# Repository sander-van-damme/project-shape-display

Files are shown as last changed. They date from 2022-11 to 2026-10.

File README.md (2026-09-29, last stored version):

<!-- © 2024 Sander Van Damme - All Rights Reserved. -->

# D&D battle-map shape display

This repository develops a tabletop shape display for physical Dungeons & Dragons battle maps: a dense grid of square or rectangular columns that can form terrain, walls, platforms, stairs, pits and other relief while remaining usable with miniatures.

## Engineering flow

The numbered root directories are intentionally ordered. Read them as the project argument from problem definition to integrated designs:

1. [`01-project-description/`](01-project-description/) — what is being built and why, including the [standing Board mandate](01-project-description/board-mandate.md).
2. [`02-design-criteria/`](02-design-criteria/) — requirements, scale, fabrication context and success criteria.
3. Engineering knowledge used to construct solutions:
   - [`03-engineering-knowledge/`](03-engineering-knowledge/) — knowledge model, sources and cross-cutting synthesis.
   - [`03.1-engineering-disciplines/`](03.1-engineering-disciplines/) — analogous engineering fields.
   - [`03.2-engineering-mechanisms/`](03.2-engineering-mechanisms/) — concrete reusable mechanisms.
   - [`03.3-engineering-principles/`](03.3-engineering-principles/) — transferable design principles.
4. [`04-architecture-candidates/`](04-architecture-candidates/) — Shape Display-specific combinations of mechanisms and principles.
5. [`05-research-questions/`](05-research-questions/) — unresolved hypotheses, investigations and research directions.
6. [`06-experiments/`](06-experiments/) — calculations, simulations, CAD, prototypes and physical tests that generate evidence.
7. [`07-evidence-and-decisions/`](07-evidence-and-decisions/) — consolidated evidence, architecture investigations and durable decisions.
8. [`08-integrated-designs/`](08-integrated-designs/README.md) — the **single stage for complete machine architectures**. Stage 08 may hold **multiple** integrated-design packages, each with its own status (see the [stage index](08-integrated-designs/README.md)); a design becoming integrated does **not** delete or overwrite previous integrated designs.

The numbered flow **terminates at 08**. A new machine architecture does **not** receive a new
numbered root directory — see [New designs do not get new numbered stages](#new-designs-do-not-get-new-numbered-stages) below.

## Core target

The detailed requirements live in [`02-design-criteria/README.md`](02-design-criteria/README.md). The current target includes approximately 400 × 400 mm active area, about 5.08 mm or finer pitch, roughly 6,200–6,400 cells at full scale, at least 40 mm provisional vertical travel, regional updates, a playable full-map change in under 30 seconds, and tight purchased-component cost limits.

## How knowledge should move

```text
project description
  -> design criteria
  -> disciplines
  -> mechanisms
  -> principles
  -> architecture candidates
  -> research questions
  -> experiments
  -> evidence and decisions
  -> integrated designs (08, may hold several)
  -> new questions / updated knowledge
```

Experiments are evidence, not the primary place to store durable engineering knowledge. Conclusions that survive testing should be fed back into the relevant mechanism, principle or architecture section.

## New designs do not get new numbered stages

The root numbers describe the **engineering lifecycle**, not architecture versions. Do not
create `09-*`, `10-*`, `11-*`, … for a new machine.

- A new **idea / mechanism / system concept** belongs in [`04-architecture-candidates/`](04-architecture-candidates/).
- Evidence-generating work (calculations, simulations, CAD, screens, falsification tests)
  belongs in [`06-experiments/`](06-experiments/).
- Durable conclusions, comparisons and selection/rejection decisions belong in
  [`07-evidence-and-decisions/`](07-evidence-and-decisions/).
- Only an architecture that has matured into a **complete machine** is placed under
  [`08-integrated-designs/<semantic-design-name>/`](08-integrated-designs/README.md).
  Use meaning-bearing names, never `design-1/`, `design-2/`, or a new number.

Promotion into stage 08 requires at minimum a coherent full-system mechanism, interaction with
all important product requirements, timing/cost/scalability/reliability analysis, explicit
unresolved risks, enough CAD/calculation evidence to evaluate the architecture, and an
evidence/decision record explaining the promotion. Stage 08 must not be flooded with raw
exploration.

## Agent autonomy and repository operations

This repository is an autonomous engineering workspace. Paperclip agents are trusted to manage
ordinary repository work without waiting for board approval or rejection.

- Agents may create, modify, move, or delete repository files; create branches and commits; open,
  update, review, close, and **merge pull requests themselves**.
- **No board approval is required for merges, ordinary refactors, experiments, design decisions, or
  promotion of an architecture when the documented engineering evidence supports it.**
- Branches, PRs, reviews, and checks are useful for traceability and engineering quality; they are
  **not permission gates**.
- Do not block ongoing work waiting for a board response. Escalation is reserved for genuinely
  exceptional actions outside normal project iteration (for example, destroying/replacing the
  repository as a whole).
- Never commit credentials, tokens, private keys, or other secrets.

## Useful entry points

- [Design criteria](02-design-criteria/README.md)
- [Engineering knowledge model](03-engineering-knowledge/README.md)
- [Architecture candidates](04-architecture-candidates/)
- [Research questions](05-research-questions/)
- [Experiment guide](06-experiments/README.md)
- [Evidence and decisions](07-evidence-and-decisions/)
- [Integrated designs (stage 08)](08-integrated-designs/README.md)

## Copyright

© 2024-2026 Sander Van Damme - All Rights Reserved.

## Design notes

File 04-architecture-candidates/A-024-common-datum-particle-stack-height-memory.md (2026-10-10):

---
status: candidate
builds-on: [M-001, P-009]
---

# Common-datum particle-stack height memory

A column follower rests on a counted stack of spheres in a vertical tube. The
number of particles stores height; compressive contacts and a grounded bottom
fork support the load. A travelling row of feeders docks at the **fixed bottom
of every stack**, avoiding acquisition of a foot at an unknown height. This is
solid-length storage, distinct from trapped fluid, tensile winding and the
binary moving structural layers. The follower needs guidance and a downward
return bias; particle removal alone cannot pull a jammed follower down.

Proposed transaction: a pocketed pusher supports the stack, unloads the fork,
transfers one particle in/out, returns the grounded fork, seats and proves support,
then repeats or undocks. Two support levels are needed during exchange; the fork
cannot simply withdraw beneath a loaded stack. Shared powered feed strokes plus
individually selected head couplings provide addressing. Unchanged forks remain
engaged. The transfer, return, actuator arrest and retained selection are open
mechanisms, not supplied by the existence of beads or a clearance section.

Count pulses are insufficient readback: use an underside follower-height mark
and support-proof step before undocking. A missed/doubled particle, bridging or
false acceptance leaves a wrong or unsupported cell. Stop with the head supported,
retain selection, reverse at most one transfer after readback, then isolate and
service the tube. A common reader/feed fault may affect an entire bank. Shared
reservoir and recirculation must work on repeated arbitrary maps, including an
all-high map; spare storage cannot be omitted.

E-126 rejects the bounded **four-rest-to-rest-stroke feeder** on throughput,
including 320 heads. It does not reject continuous pocketed feeding. The tested
4-mm sphere scenarios need 11 particles per site to guarantee geometric reach
above 40 mm before elastic compression: 70,400 particles, 6,400 slotted tubes and
forks, return elements, plus feeders, selectors, sensors and a circulation path.
E-130 tests a level translating pallet and a circular pocket path at two retained
heights in both directions. Grounded endpoint seats admit sphere-contact paths,
but intermediate input removal still needs linear restraint or rotary arrest;
inline repetition also intersects an unchanged upstream stack. Captivation alone
does not ground the moving support. Stop these embodiments, not every solid-length
mechanism. Reopen only with a changed grounded-support/arrest path and explicit
feed routing that escapes both these failures and the serial-cycle bound.
No print, purchase or reliability claim.

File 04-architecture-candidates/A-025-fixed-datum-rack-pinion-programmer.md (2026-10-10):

---
status: candidate
builds-on: [A-007, A-013]
---

# Fixed-datum rack-and-pinion programmer

Each guided column carries a full-travel rack engaging a **stationary pinion**.
A travelling row bank docks rotary drives to pinion shafts at one common height.
The rack moves; the docking shaft does not. A positively retained ground bolt
arrests the shaft/gear between updates. Unlike A-007's screw, displacement per
turn is the pinion circumference; unlike A-013's foot clamp, docking need not
follow the column's previous height. This is a topology recombination, not a new
gear principle or a reopening of the rejected screw geometry.

Sequence: dock keyed drive → take load → unload/retract only the addressed bolt
→ turn pinion to target → reinsert bolt → seat/prove ground support → verify
rack height → undock. An independently retained selection state survives proof.
Bilateral powered drive and an arrested drive shaft are needed while the ground
bolt is open, including loss of power. E-127 constructs a nominal single-head
powered contact sequence; a spring-return ground bolt is blocked at mid-index
and does not supply continuous passive arrest. Bolt actuation and its grounded
guide remain unbuilt.
A shared rotating bus with selectable head clutches is the economical hypothesis;
independent drives are the timing control, with no affordable BOM yet.

Load path: cap → rack teeth → pinion → shaft bearings/positive arrest → module
frame. Unselected bolts stay locked during regional updates. Repeat 6,400 racks,
pinions, bearing sets and arrests; teeth/backlash/wear and shaft alignment replace
the jaw-acquisition problem. Internals may be staggered beneath 5.08-mm tops,
but no tileable mesh/shaft/bolt package is demonstrated. A 3-mm pitch diameter gives
4.24 turns per 40 mm and about 1,910 rpm at 300 mm/s, **kinematic assumptions**,
not a motor or printable-gear qualification.

A rack mark plus ground-support proof must detect docking/mesh skips and false
bolt seating; motor angle alone does not prove height or support. On disagreement
keep the drive supported/arrested and selection retained, attempt one controlled
reseat, then stop/service the module. Common registration or reader failure can
corrupt a row. E-126's continuous-motion bound remains conditional.

E-127 rejects simultaneous engagement of its six-dog rigid bank to shafts 30°
apart. Matching twelve ground slots to twelve dock dogs removes that nominal
phase conflict, yielding a 1.88496-mm height grid with a 7.2-mm pitch-diameter
pinion. This is an unapproved discrete terrain option, not arbitrary-angle
coupling. Its dock fit fails the labelled ±.05-mm error scenario. Two axial
gear lanes clear gear envelopes but the tested straight shaft hits the adjacent
rack backing by .62 mm. Neither result rejects other shaft routes or gear forms.

E-128 changes routing to outward-facing pinions: two local shafts clear their
rack backings by 3.30 mm, but naive same-tier pair replication overlaps solid
pinion roots by 4.08 mm. This is local access, not board packing. Its finite
annular friction dock (outer radius 3.4 mm, 20-N clamp, mu=.1) transmits at most
6.8 N·mm under any contact-pressure distribution, below the 11.772 N·mm demand
of the 3.27-N scenario. An independently phased sleeve with the same proximal
friction joint merely relocates that failure. Greater clamp force or a different
capture changes the case; friction coupling generally is not rejected.

Matched dogs remove that friction cut but retain E-127's fit failures. E-128's
explicit spring-pad model has a finite zero-contact interval on power loss;
continuously applied drag instead has conditional holding force and dissipation
cost. Neither is an admitted shared arrest or complete two-site machine. Keep
matched-index and independently powered positive heads as comparisons. Stop
single-face/20-N low-traction docking and free-sleeve relabeling. Reopen only with
actual clamp/reaction or positive capture geometry, replicated routing and arrest
through handover.

E-129 constructs an opposed roller/input-peg joint: nominal static hold passes,
but a 20-N extractor cannot release its loaded high-friction scenarios;
a successful release opens a finite branch with no resisting torque for loaded
lowering. Alternating fixed ground bolts also lack the proposed overlap-first
transfer. Neither result rejects all no-back brakes or escapements. Independent
positive heads with permanent local drag retain conditional support at explicit
force/heat cost, not machine acceptance. Stop this rotary-arrest refinement and
change the next common-datum retention investigation to captive solid-length
exchange (E-126/A-024). Reopen only with a changed anti-overrun/support-transfer
topology, not retuned roller sizes. No schedule, BOM or fabrication justified.

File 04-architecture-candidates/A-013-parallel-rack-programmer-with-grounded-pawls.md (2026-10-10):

---
status: candidate
builds-on: [A-003, A-007, A-012]
---

# Parallel rack programmer with grounded pawls

A travelling underside head bank independently grips column tails, unloads their positive pawls, retracts only those pawls, moves the columns to selected teeth, re-engages support and releases. Five provisional states at 0/10/20/30/40 mm; the requirements do not mandate five states. Each column has a rack, replaceable rigid pawl and guide. Service load closes through the pawl into a distributed base grid. A weak return element locates the pawl but must not carry service force. Inactive cells stay latched.

Unlike A-003's rejected printed shutter/register fanout, this embodiment uses independent linear positioning and pawl-release channels on 80 or 160 reusable heads. It trades selector complexity for expensive head count; it is a distinct embodiment within the travelling-writer family, not a newly discovered principle. Staggered actuators and links below the field must still be packed and checked. No existing 71-cell/s writer rate is inherited.

Sequence: acquire tail → confirm grip → slightly lift to unload → retract pawl → position → engage pawl → seat and verify height/support → release grip → return head → index. The motion budget includes an 80-mm total positioning path; separate engagement/seat time must cover unloading and recovery. Five-state arbitrary transitions are reachable in the abstract support-state machine. Physical contact continuity, release link collision, out-of-plane motion and acquisition over differing initial heights are unverified.

Head encoders plus an underside optical mark reader compare commanded and observed position before release; a short support-proof displacement/force check is needed to distinguish a supported column from a gripper-held column. Its timing is within the declared read/contact allowances, not established hardware capability. Failed reads retain grip and allow bounded retry; persistent faults stop the bank. A false support acceptance can drop a cell. Common registration/reader errors can affect a whole row. Replaceable underside row cartridges permit service but require access below the board.

Potential advantage: no physical mask transport, no 6,400 purchased actuators, direct arbitrary regional updates and positive local load support. Main liabilities: 6,400 pawls/returns, at least 19,200 critical guide/latch/grip interfaces, demanding head packing and unaffordable actuator count unless channel cost falls sharply. No product selection or print release follows from this proposal. E-050 is the first necessary-condition screen; Q-012 governs the next mechanism question.

E-053 rejects the fixed same-plane rear guide at the middle/wide placement bounds: even zero bearing span needs 5.25/7.00 mm against 5.08-mm pitch. The tight bound permits a conditional 4.75-mm section with 0.9-mm engaged guide allowance, not an assembled or load-qualified guide. Continue only with 3D/staggered support packaging or evidence for smaller error; do not extend E-052’s middle witness into a same-plane head.

E-054 side-cheek rails escape the rear-guide obstruction. Equal 0.4-mm walls/shelves fail the assumed 10-N/8-MPa strip-bending screen, but decoupling shelf thickness to 0.8 mm retains the same 4.89 × 5.00-mm middle-bound footprint and avoids that rejection. Retain this conditional geometry; next resolve side-wall grounding, plate/contact behavior, loaded rotation and complete channel cost. Do not promote it or print from clearance alone.

E-055 finds no opposing-shelf pitch stop; E-056 nevertheless establishes conditional seated vertical-load equilibrium on the lower shelves. Arbitrary edge pressure has zero guaranteed pitch margin, so neither clearance nor static equilibrium proves reliable support. E-057 rejects robust inset-pad support at inherited overlap; retain the slot as a comparator and keyed/staggered guidance as the geometric alternative with explicit unloaded capture, return and retention. Q-012 retains the complete channel-cost and support-sequence gates before FEA or printing.

E-050’s joint timing/cost extension admits a conditional 240-head central-motion comparator, but only $1.0417 per complete channel at a $250 shared reserve and $500 cap before cell purchases. The next gate is complete-channel costing and bank-load-dependent motion, ahead of further pawl refinement. Increasing head count is not a demonstrated system rescue.

E-059 rejects the sourced FS0307/FS90 servo-per-head procurement route:
80 positioning actuators alone cost $748/$632 at observed public prices,
above the entire $500 cap. This excludes these priced embodiments, not all
independent drives. Stop their layout work; reopen with a complete cheaper
channel or changed addressing/schedule. Shared-energy selection remains a
separate mechanism question with E-051's support-proof dwell gate.

E-115 retains a powered pivot-pawl section as a changed support alternative,
but its assumed gravity-return drag allowance is only 0.161–2.863 microN at the
tip. A compact toggle crossbolt retains only tight-bound section cases and no
demonstrated unloaded command retention. Keep the rectangular crossbolt as the
primary comparator for finite positive set/return coupling. Selection must
persist through ground reseat, support proof and selective carrier release;
direct ground=not-command coupling fails that sequence. These local results
do not reopen the rejected purchased servo route or establish a machine.

E-123 supplies finite acquisition evidence for the previously abstract direct
head: a shallow side shoe can approach at arbitrary old foot heights through
inter-row aisles while inactive heads stay below all feet. Tight translation/face
bounds admit sections, but a continuous packing bound excludes this compact
family at ±.10 mm; guide rotation and drive remain unresolved. A centered pad
clears wider errors but cannot force descent; the captured shoe has .8-mm nominal
vertical play. A common-datum rack pickup preserves indexed phase but crosses
its closed guide. Retain these interfaces for finite guidance, powered capture
and ground-lock proof, not as a complete channel or a reopening of E-059's priced
servo route. No inherited E-099 time pass or hardware qualification follows.

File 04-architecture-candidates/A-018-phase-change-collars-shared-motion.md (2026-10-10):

---
status: candidate
builds-on: [P-001]
---

# Phase-change collars with shared motion

**Bounded; not rejected as a physical principle.** Descriptors: isolated local
heaters; frozen collar height memory; shared elevator mechanical energy;
collar shear into frame as service load path; one prismatic pin and one sealed
annulus/heater per site. This replaces a mechanical pawl, not the 40-mm drive.

A sealed fusible collar surrounds a rough/keyed metal tail inside a grounded
cup. While an elevator collet holds the selected pin, an addressed heater melts
its collar, allowing translation. The collet then drives down/up to arbitrary
height and retains load during cooling. Solidification transfers load through
the keyed collar to the cup/frame; proof unloading must precede disengagement.
Adjacent heaters stay off and cups need thermal breaks. Shared cold plates
must not move unchanged pins. Active-matrix electrical isolation is required;
passive resistor coincidence is not a demonstrated selector. Recovery remelts
and reseats a failed collar while gripped; leaking cartridges require mechanical
service catches and replacement. Read tail marks and collar resistance/
temperature, but temperature is not proof of shear strength or complete freeze.

A 3-mm tail with 0.1-mm radial annulus and 2-mm collar length contains about
1.95 mm³ (exact annulus); outer metal envelope 3.2 mm leaves 1.88 mm for cup,
heater, insulation and pitch clearance. 10-N support over roughly 19 mm²
interface requires about 0.53 MPa mean shear before stress concentration/creep.
This is an assumed research load, not measured bond strength. Tail track and
collet space add depth as in the shared-elevator comparators.

Repeat 6,400 cups, seals, alloy charges, heaters, sensing/drive connections
and collet interfaces. Shared lift, cooling hardware and scanner remain.
E-063 varies phase-change enthalpy density 0.2–1 J/mm³ and volume 0.5–10 mm³
as explicit generic bounds, not alloy data: 0.64–64 kJ/map, 21–2,133 W average
at 30 s before losses. A small collar is not automatically thermally fatal;
large collar/weak sink cases require up to 250 s optimistic cooling. Thermal
bridges that accelerate cooling also spread unlock heat. Containment/wetting,
freeze shrinkage, creep and repeated sliding make an FDM cup alone unqualified.

Gallium's approximately 29.765°C melting point excludes an uncooled gallium
service lock in a 30–35°C room scenario. This is a conditional environment
failure, not a specified room limit. A higher-melting alloy avoids it but
raises heating and PLA-isolation burdens. Thermoplastic locks similarly need
measured creep and solidification strength; conductivity cannot be assumed.
No credible component quote supports the $0.0391/site residual at $250 reserve.
Retain microvolume collars only as a bounded alternative; next discriminate
minimum load-bearing keyed volume against heat-sink/cross-talk requirements.

Primary leads: [submillimeter alloy catheter](https://pmc.ncbi.nlm.nih.gov/articles/PMC8456283/)
demonstrates small-scale stiffness control, not a sliding pin lock;
[NIST gallium standard](https://www.nist.gov/publications/standard-reference-material-1751-gallium-melting-point-standard)
establishes the melting temperature. Accessed 2026-10-08.

## Inverse annulus load/energy bound

Initial successor calculation at input main `50b81ee`; analytical necessary
bound and self-review, not material or contact evidence. Under an effective
allowable cylindrical interface shear stress τ, tail diameter d, radial alloy
gap g and supported force F, `L >= F/(π d τ)`. An annulus at that minimum length
has `V >= (F/τ)(g + g²/d)`. Thus shrinking the tail diameter does **not** reduce
minimum material/heat at fixed load, gap and allowable stress: required length
increases and the small curvature term gets worse. Gap, effective strength and
load allocation control this bound. Discrete keys or bridges can change the
failure section and must be modeled as different geometry, not credited from
this cylindrical formula.

At illustrative F=10 N, g=.1 mm and τ=.5 MPa, d=3 mm requires L≥2.1221 mm and
V≥2.0667 mm³. Reducing d to 1 mm increases L to 6.3662 mm and V to 2.2 mm³.
Using E-063's **assumed** .5 J/mm³ effective heating requirement, the 3-mm case
requires ≥6.613 kJ/full board and ≥220.44 W average over 30 s, before heating
the tail, cup, substrate or compensating losses. At g=.15 mm and τ=.25 MPa,
V≥6.3 mm³ and the same calculation gives 20.16 kJ / 672 W. There is no stage-02
power cap; these numbers are heat/circuit/cooling obligations, not rejection
criteria. Simultaneous release, repeated group operations and recovery may
raise peak power or total heat. The stress scenarios are not alloy strength,
creep allowables, adhesive qualification or a probability distribution.

Reproduce the inverse result and verify against independent annulus volume:

```python
from math import pi, isclose
for d, g, tau in [(3, .1, .5), (1, .1, .5), (3, .15, .25)]:
    length = 10 / (pi*d*tau)
    volume = pi*((d/2+g)**2-(d/2)**2)*length
    assert isclose(volume, 10/tau*(g+g*g/d))
    print(length, volume, 6400*volume*.5/30)
```

## Current disposition after finite containment search

**Studied embodiments parked; thermal-support campaign technically concluded
(ADR-019).** The physical family remains bounded, not disproven. No informative
complete containment/material-cycle survivor warrants thermal tuning or printing.

E-110's finite keys give positive support but add molten transport and frozen
obstruction. Its holdout contains 13.283–13.635 mm³ and fully filled translating
grooves could export 28.149 mm³ over 40 mm. E-111's sealed full-track bath closes
geometric inventory at roughly 120 mm³ and 85.6-mm length; a drain/return escape
remains unqualified. These are conditional geometric bounds, not measurements.

E-111–113's dry-jaw thermal strut removes the long wet pin but introduces two
moving boundaries per site. Generated supported rolling/sliding packages with
roof ports and return at .05-mm error span 4.128/4.596 mm against a 1.89-mm side
bay, holding 6.598/6.671 mm³. Freeze sequence, creep, compatible seals and the
12,800-boundary process remain unresolved; cap-only volumes were optimistic.

E-114 tests a genuinely different fixed open capillary accumulator. Nonwetting
bores can return liquid under positive pressure while narrower jaw gaps resist
escape: its nominal clean-interface pressure margin is 621 Pa, with 5.621 mm³
charge. A .05-mm scenario reduces that margin to 4.4 Pa at the tested motion
load; slower motion can rescue that pressure case. Crucially, the finite stem
can carry liquid past its fixed hot lip into a cold guide. Static wetting angles
and aggregate reservoir capacity do not close the repeated material cycle.
This preserves a conditional capillary opportunity, not a machine survivor.

Reopen only with changed complete return/retention/isolation geometry or
credible interface evidence and an affordable repeated process. Do not infer
perfect drainage, liquid-volume closure through frozen paths, or durability
from analytical acceptance. A dry positive crossbolt remains the simpler
unqualified comparator. Next portfolio allocation is passive positive support
with shared selection/reset; earlier addressing and timing failures still apply.

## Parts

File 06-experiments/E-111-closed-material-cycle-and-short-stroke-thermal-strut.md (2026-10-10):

---
status: complete
builds-on: [E-110, A-018, A-017]
---

# Close the material cycle before optimizing thermal release

Input main `629f70b`. **A finite sealed bath can eliminate E-110's modeled
external groove transport, but its whole-bath implementation heats about nine
times the local collar inventory. A short-stroke thermal structural strut is a
more informative next geometry investigation, conditional on a finite flexible
boundary and service creep.** Neither implementation passes a complete-machine
gate. No new material properties, physical measurements or qualified seals.

Reproduce: `python3 tools/curated-experiment-checks/E-111/material_cycle.py`;
`--all` includes all 81 deterministic strut parameter cases. These are one
strut topology, not 81 architectures. Source retains generator, units, bounds,
rejection reasons and verification; no random distributions or seed.

## Separated seals and enclosed return

Keep E-110's R=1.5, radial gap=.1, key depth=.2, width=.4, period=1 and
collar L=5.2 mm. For S=40-mm travel, the finite keyed tail must span L+S=45.2
mm. Its swept interval is L+2S=85.2 mm. With .2-mm end margins, fixed seals
can be placed **85.6 mm apart on smooth lands** without any groove crossing
either seal. Each smooth land must span at least 40.2 mm, plus the seal's
finite contact width and registration allowance. Minimum modeled tail length
is 125.6 mm before those additions. Equal-area through-rods cancel net piston
displacement. Both dynamic seals remain material/friction/wear obligations.

Exact interval integration gives 119.732–120.084 mm³ liquid over groove phase:
83.365 mm³ smooth annulus, plus all moving groove inventory and local cup
keys. The groove inventory stays inside the cartridge at every intermediate
stroke; it no longer leaves with the rod. This closes the **geometric inventory**
cycle, assuming the sealed bath is completely filled and every obstructing
volume is molten. Expansion and freeze shrinkage still require accommodation.

The modeled whole bath uses 384.27 kJ/board, or **12.809 kW averaged over 30 s**,
at E-063's generic .5 J/mm³ assumption. The 30-s denominator is a favorable
limit, not a demonstrated <30-s schedule; colder structure, cooling and repeated
cycles add burdens. This is about nine times E-110's 13.283–13.635-mm³ local
holdout. No stage-02 power ceiling permits declaring the physical family
impossible from wattage alone. Deprioritize this embodiment because its resolved
transport problem creates a much larger energy/cooling and wet-depth burden.
Reopen with demonstrated local drainage/return or another geometry reducing
heated inventory without leaving frozen material in the translating groove path.

A local drain reservoir alone does not resolve that path. E-110's frozen-solid
intersection remains if material carried beyond the heater freezes in a groove.
Perfect drainage and full entrainment remain competing unmeasured cases. A
continuously heated gutter or nonwetting drain might change this, but neither is
credited without a finite return path and a bounded retention/entrainment model.

## Enclosed short-stroke structural strut

Changed operating principle: a dry rack's sloping shoulder rests on a guided
retracting jaw. The guide transfers vertical service force to ground. The
shoulder also pushes the jaw outward; a sealed **solid phase-change strut**
between jaw and frame carries that horizontal component. For an ideal
frictionless shoulder at angle α from horizontal, `H=F tan(α)`. At F=10 N and
α=30°, H=5.774 N. The thermal material is in the service load path. At α=0 this
advantage disappears: it reduces to a supported mechanical latch needing only
a release command, already represented by A-017. Friction and ramp compliance
are not credited as extra holding capacity.

A collet first takes vertical load and unloads the shoulder. Melt the strut,
withdraw the jaw by engagement plus clearance, translate the dry rack, reseat
the jaw, restore the material and freeze. Proof unload before collet release.
A drive and return spring/cam must supply withdrawal and reservoir forces;
melting itself supplies no motion. Individual heaters need electrical isolation;
unchanged jaws remain frozen and supported. Failed freeze retains collet support;
a stuck-on heater needs a mechanical service catch. Schedule, catches, guides,
readback false acceptance and recovery have not been solved by this calculation.

Reduced capsule representation: two equal-area, variable-length liquid chambers
connected by an internal duct. Their caps attach to sealed flexible boundaries,
not a grooved sliding feedthrough. Main chamber length is `h+s−x`; reservoir
length is `h+x`, for `0≤x≤s`. Thus `V=A(2h+s)+Vduct`, independent of stroke.
Molten material transfers `A s` each withdrawal and returns on seating; there is
no modeled external export. A rigid fixed-volume capsule with no moving reservoir
**cannot** accept that displacement for incompressible liquid. A nominally empty
reservoir is not a demonstrated return mechanism.

These are exact fluid-domain volumes and rigid-cap sweeps, **not generated
flexible membrane surfaces or an accepted seal**. Bellows/diaphragm folds,
attachments, rupture, buckling, contact, fatigue and their true displaced volume
remain unresolved. The compactness screen only allocates .3 mm around each cap;
it does not pack both chambers, the rack, guides, actuator and duct at pitch.
The reservoir can be staggered in depth, but its finite route must be generated.
Frozen load transfer assumes a fully connected filled solid; voids or creep
through the duct can defeat it. The effective allowable stress below is a
whole-strut hypothesis including those effects, not a compressive material test.

## Bounded comparison and sensitivity

Generator: α=15/30/45°; effective stress σ=.25/1/5 MPa; coherent error
e=0/.05/.15 mm; added dead-volume fraction=0/.5/1. Radius is resized to
`sqrt(H/(πσ))+e` so the smallest bounded radius still meets the assumed load
cut. Stroke `s=.3+.15+e` mm; end gap h=.2 mm. Duct is .8×.2×2 mm. The same e
also closes its height. This is conservative design sizing and a correlated
corner scenario, not predicted manufacturing yield. Dead volume is a sensitivity
allowance, not a verified upper bound on membrane or expansion-reservoir volume.
18/81 cases exceed the cap-only 5.08-mm radial allocation; all are weak-stress
30°/45° cases. Other cases are merely not rejected by this necessary screen.

At α=30°, 50% added dead volume:

| Effective σ MPa | e mm | Inventory mm³ | Cap radial allocation mm | Ideal board W / 30 s |
|---|---:|---:|---:|---:|
| .25 | 0 | 29.925 | 6.023 — fails | 3192 |
| 1 | 0 | 7.841 | 3.311 | 836 |
| 1 | .05 | 8.860 | 3.411 | 945 |
| 1 | .15 | 11.163 | 3.611 | 1191 |
| 5 | 0 | 1.952 | 1.813 | 208 |
| 5 | .05 | 2.307 | 1.913 | 246 |
| 5 | .15 | 3.175 | 2.113 | 339 |

Against E-110's 14.608-mm³ middle-strength/.05-error annular grid minimum,
the middle strut has less **assumed** inventory. The stresses describe different
failure modes; no measured strength equivalence or dominance is implied. A
mechanical jaw has zero phase-change heating but retains actuation/addressing
burdens. The whole bath closes geometric transport with dynamic seals; the
strut trades those seals for two flexible moving boundaries per cell. There is
no defensible cost/reliability winner yet.

For 0.5-s liquid transfer, rectangular-duct Stokes flow gives middle/.05-error
forces of .000777/.00777/.388 N at assumed viscosities .002/.02/1 Pa·s. At
.15-mm coherent closure the .2-mm duct shrinks to .05 mm; the 1-Pa·s force rises
to **15.207 N**, before membrane, return, bends, wetting and shoulder friction.
This reverses any claim that short travel implies negligible actuation force.
The viscosity range is a scenario, not alloy/polymer data; non-Newtonian flow,
partial freezing and solid debris are outside this model. Transfer time is an
input, not a full-map timing result. The exact rectangular series corrects the
infinite parallel-plate conductance for sidewalls; reducing height has cubic
leading sensitivity. A closed duct is an explicit failure, not infinite flow.

Equal nominal volumes also do not remove manufacturing/thermal accommodation.
For cap radii r+b±d, a prescribed paired stroke s leaves mismatch
`ΔV=4π(r+b)d s`: common radius bias b alone cancels; differential mismatch d
combines with it. The middle/.05 case with d=.05 mm needs .442 mm³ compensation.
An additional **assumed ±5%** material-volume excursion adds .443 mm³. Together
these require up to .1533 mm extra reservoir travel using its smaller cap area,
if both adverse extrema coincide. This extra envelope is not included in the
nominal cap packing. A free reservoir can take unequal travel; forcing equal
travel with a rigid linkage instead creates pressure/void risk. Accommodation
on both sides of the cycle is required; the sign of expansion is not assumed.

All scenarios can apply to every cell in a print/material batch. The computation
does not multiply independent success probabilities. Thermal expansion,
solidification density change, creep, wetting, gas voids and membrane life need
material-specific evidence. X1C dimensional spread, layer/warp effects and
anisotropy are not represented by a calibrated distribution; no FDM thin-membrane
claim is made.

## Full-board decision and next discriminator

The strut repeats at least **12,800 flexible boundaries**, 6,400 liquid return
paths/charges, heaters, isolated switches and jaw/guide interfaces, before collets,
sensors, service catches and shared motion. With an illustrative $250 shared
reserve, the remaining <$500 bought budget is <$0.0391/site; if the two boundaries
alone consumed it, each would need to cost <$0.0196. This is a budget division,
not a quote or a rejection of integrated sheet manufacture. Lamination/sealing,
fill/degas, inspection, cartridge repair and thermal isolation are major burdens.
Do not call reduced heating an affordability result.

Continue the existing A-018 campaign with a **finite sealed strut boundary,
reservoir return and jaw packing gate**, alongside a simple mechanical-jaw
comparator. It must close the .15-mm-scale mismatch/expansion allowance without
reintroducing 40-mm wet motion, preserve the solid service load path, and show
an affordable repeated boundary process. Stop this strut implementation if no
such geometry survives; do not substitute a command-only thermal latch and call
it a new architecture. Only then is a transient thermal discriminator informative.
No print or purchase is justified by this inventory screen.

## Verification and evidence limits

Independent midpoint integration at 10k/100k/1M slices on three off-grid finite
bath holdouts has maximum errors .013411/.002056/.000376 mm³. All checked
translations preserve exact inventory; seal-clearance inequalities cover the
entire swept interval. Capsule checks conserve volume over 101 stroke states;
analytical identities cover the intervening continuum. Mismatched areas and
blocked ducts are fault cases. Checks include linear pressure scaling in flow
and viscosity, the independent parallel-plate pressure bound and α=0's
command-latch limit. No membrane/contact solver, thermal model or independent
review ran. Self-review validates the stated reduced calculations, not hardware.

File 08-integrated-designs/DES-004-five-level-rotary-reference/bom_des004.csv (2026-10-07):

scenario | row_type | line | qty | unit_usd | ext_usd | evidence | price_basis | source_or_note
baseline | component | Existing DES-003 purchased BOM | 1 | 370.00 | 370.00 | sourced-allowance | DES-003 bom_a1.csv subtotal | 08-integrated-designs/DES-003-reliability-first/bom_a1.csv
nominal | component | Existing DES-003 purchased BOM reused | 1 | 370.00 | 370.00 | inferred-reuse | No new purchase for retained gantry motors guides electronics 8 writer/reader positions | DES-003 bom_a1.csv
nominal | component | Metal rotor axle pins | 6400 | 0.020 | 128.00 | estimate | Target bulk-cut/debur allowance; supplier quote and availability unresolved | 6400 cells x 1 axle
nominal | subtotal | Nominal DES-004 purchased total | 1 | 498.00 | 498.00 | calculation | 370.00 + 128.00 | Calculated scenario total; exclude subtotal rows when summing components
conservative | component | Existing DES-003 purchased BOM reused | 1 | 370.00 | 370.00 | inferred-reuse | Same retained purchased system as nominal | DES-003 bom_a1.csv
conservative | component | Metal rotor axle pins installed | 6400 | 0.050 | 320.00 | estimate | Small-quantity cut/debur allowance; supplier quote and availability unresolved | 6400 cells x 1 axle
conservative | component | Service writer actuator spare | 1 | 9.00 | 9.00 | sourced-allowance | Same class as DES-003 writer toggle actuator | DES-003 bom_a1.csv
conservative | component | Service reader head spare | 1 | 12.00 | 12.00 | sourced-allowance | Same class as DES-003 reader head | DES-003 bom_a1.csv
conservative | component | Service driver module spare | 1 | 2.00 | 2.00 | sourced-allowance | Same class as DES-003 DRV8833-class module | DES-003 bom_a1.csv
conservative | component | Axle scrap/service stock | 320 | 0.050 | 16.00 | estimate | 5% quantity allowance; order quantity is 6720 pins total | supplier quote and availability unresolved | 6400 installed + 320 spare/scrap
conservative | subtotal | Conservative DES-004 purchased total | 1 | 729.00 | 729.00 | calculation | 370.00 + 320.00 + 9.00 + 12.00 + 2.00 + 16.00 | Calculated scenario total; exclude subtotal rows when summing components

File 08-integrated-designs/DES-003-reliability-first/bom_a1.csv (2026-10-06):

line | qty | unit_usd | ext_usd | evidence | use
X gantry stepper (NEMA17-class) | 1 | 14.00 | 14.00 | sourced-class | gantry across 406.4 mm X
Y/head-traverse stepper (NEMA17-class) | 1 | 14.00 | 14.00 | sourced-class | head across Y lanes
Writer toggle actuator (small stepper/servo) | 8 | 9.00 | 72.00 | sourced-class | over-centre latch toggle force
X guide rail pair + bushings (400 mm) | 1 | 22.00 | 22.00 | sourced-class | gantry rigidity
Y guide rail + bushings (400 mm) | 1 | 16.00 | 16.00 | sourced-class | head traverse
Timing belt + 2 pulleys (X) | 1 | 8.00 | 8.00 | sourced-class | gantry drive
Timing belt + 2 pulleys (Y) | 1 | 8.00 | 8.00 | sourced-class | head drive
Writer head body + toggle prong | 8 | 6.00 | 48.00 | allowance | repeated head contact feature (printed body excluded, prong hardware)
Reader head (reflectance/photodiode row) | 8 | 12.00 | 96.00 | sourced-class | state readback
Controller (RP2040/ESP32) | 1 | 5.00 | 5.00 | sourced-live | RP2040 C2040
Stepper driver modules (DRV8833-class) | 3 | 2.00 | 6.00 | sourced-live | gantry + head + writer
Power supply + protection (24 V 2 A) | 1 | 12.00 | 12.00 | sourced-listing | smaller than S5's 35 VA
Wire / connectors / flex loom | 1 | 18.00 | 18.00 | sourced-class | moving gantry loom
Limit / home switches (X, Y, writer) | 5 | 1.00 | 5.00 | sourced-class | datum + recovery re-home
Frame splice hardware (printed frame excluded) | 1 | 10.00 | 10.00 | allowance | 406 mm frame printed as sub-tiles
Fasteners (M3 assortment) | 1 | 8.00 | 8.00 | sourced-class | assortment
Spares and miscellaneous | 1 | 8.00 | 8.00 | assumption | kept per prior analysis policy

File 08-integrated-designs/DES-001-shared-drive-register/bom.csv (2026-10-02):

item | quantity | unit_expected_usd | unit_sourced_usd | parts_usd | delivered_usd | evidence | note
Fixed no-channel base (E1-E6: rods, belts, shafts, fasteners, power, loom, PCBs, lift/scanner motors, controller, registers) | 1 | 218.7 | 218.7 | 218.7 | 253.69 | SOURCED-reduced | motor AND 80-channel TB6612 driver block removed
Bank motor (NEMA17-class >=0.30 N.m, 4-wire bipolar) | 2 | 12.0 | 12.39 | 24.0 | 27.84 | ALLOWANCE (working); SOURCED-LIVE $12.39 is the optimistic | cheapest torque-matched orderable 17HS4401S 42N.cm; 17HS4023 EUR4.24 is under torque. Working total uses the $12.00 allowance (prior analysis), not the $12.39 sourced copy
Writer solenoid (5 V push, >=1.2 N design target) | 40 | 2.5 | 2.2 | 100.0 | 116.0 | ALLOWANCE (working); SOURCED-LIVE $2.20 is the optimistic | price supported; force (N) not published by any listing. Working total uses the $2.50 allowance (prior analysis)
Bank H-bridge channel (TB6612FNG dual, 1 IC/motor working) | 2 | 0.7955 | 0.7955 | 1.59 | 1.84 | SOURCED (LCSC C88224) | 2 motors need 2 channels; may share 1 dual IC
Writer switch (ULN2803-class 8-channel darlington) | 5 | 0.3 | 0.3 | 1.5 | 1.74 | ALLOWANCE | ON/OFF low-side switch, not an H-bridge
Steel drive rod (sourced Ø6 mm ground rod, prior analysis) | 1 | 3.0 | 3.0 | 3.0 | 3.48 | SOURCED-class allowance | replaces the printed 3x2 placeholder bar; 6 mm x 406.4 mm cut rod, ~$6/m retail
TOTAL (WORKING scenario: prior analysis allowances + own channels + sourced steel rod) |  |  |  | 348.79 | 404.6 |  | ceiling $500 (-$95.4); ideal band $400 (+$4.6)
scenario reference (not additive) |  |  |  |  |  |  | WORKING (above) = $404.60 delivered = promoted model s5r_register.bom(4)['delivered_usd']; this is the delivered headline. OPTIMISTIC (1 shared bank IC, sourced motor $12.39 / writer $2.20) = $387.18 delivered, a reference, NOT the working scenario. The pre-prior analysis CSV's $388.10 header was the sourced-unit variant with 2 bank ICs and no steel rod; it is also NOT the working scenario. Rod-unpriced working intermediate = $401.12 (delivered_no_rod_usd).

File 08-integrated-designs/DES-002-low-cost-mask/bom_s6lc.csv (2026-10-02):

item | quantity | unit_usd | ext_usd | evidence | use
Lift motor (NEMA23-class stepper) | 1 | 30.0 | 30.0 | sourced-class | global-board lift (prior analysis branch 1); 4-screw belt-synced
Mask gate index motor (small stepper) | 1 | 8.0 | 8.0 | sourced-class | sets the 8 bank mask gates
Reset carriage motor (small stepper) | 1 | 8.0 | 8.0 | sourced-class | traverses the 8 banked release combs
4x T8 lead screw + anti-backlash nut | 1 | 24.0 | 24.0 | sourced-listing | <= 2 mm lead (prior analysis); non-racking platen
Timing belt + 2 pulleys (4-screw sync) | 1 | 12.0 | 12.0 | sourced-class | synchronises the four screws
Motor couplers + thrust washers | 1 | 6.0 | 6.0 | sourced-class | axial take-out
Guide rods + bushings (platen) | 1 | 14.0 | 14.0 | sourced-class | lateral guidance
Controller (RP2040/ESP32) | 1 | 5.0 | 5.0 | sourced-live | RP2040 C2040
Stepper driver module (DRV8833-class) | 3 | 1.59 | 4.77 | sourced-live | lift + mask + reset; no 80-channel head
Power supply + protection (24 V) | 1 | 12.0 | 12.0 | sourced-listing | smaller than S5's 35 VA
Wire / connectors / loom | 1 | 14.0 | 14.0 | sourced-class | few actuators -> small loom
Fasteners (M3 assortment) | 1 | 8.0 | 8.0 | sourced-class | assortment
Axis reference sensors | 4 | 1.0 | 4.0 | sourced-class | datum only; no per-cell feedback
Spares and miscellaneous | 1 | 8.0 | 8.0 | assumption | kept per prior analysis policy
Mask index mechanism (rack/cam + 8 linkages) | 1 | 15.0 | 15.0 | allowance | prior analysis A5: real required capability | was unlisted
Reset carriage rail + frame hardware | 1 | 20.0 | 20.0 | allowance | prior analysis A5: carriage traverses 406.4 mm | was unpriced
Thrust bearings (4x axial 2560 N) | 1 | 18.0 | 18.0 | allowance | prior analysis A5: global lift axial load, was unpriced
Homing / limit switches (6 axes) | 1 | 3.0 | 3.0 | allowance | prior analysis A5: only 4 datum sensors priced before
Cable chain / strain relief | 1 | 8.0 | 8.0 | allowance | prior analysis A5: moving reset carriage
Power connector / switch / fuse | 1 | 5.0 | 5.0 | allowance | prior analysis A5: PSU protection hardware
TOTAL purchased parts |  |  | 226.77
TOTAL delivered (x1.16) |  |  | 263.05

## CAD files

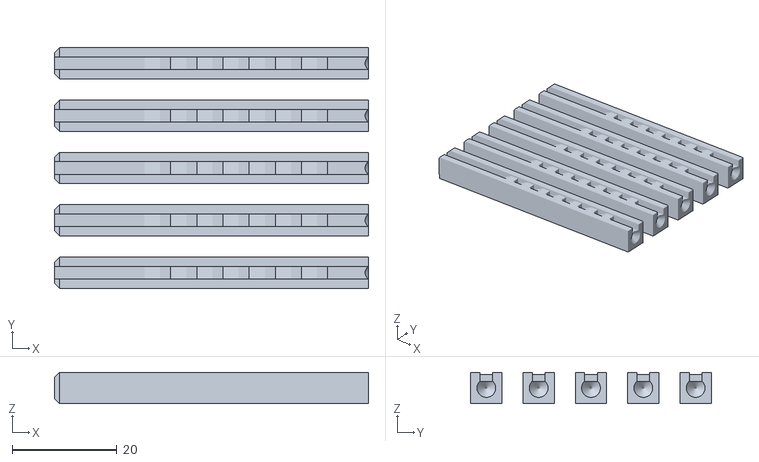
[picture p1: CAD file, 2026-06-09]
06-experiments/test06_sandwich_detent/pins_print.stl
60.0 x 46.0 x 6.00

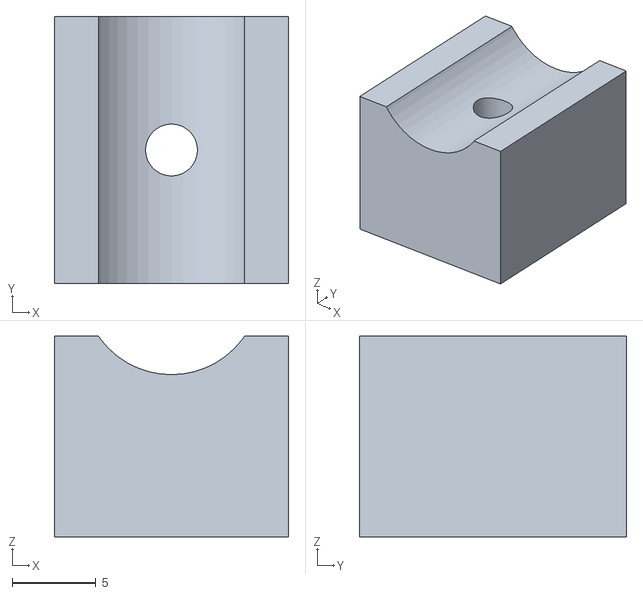
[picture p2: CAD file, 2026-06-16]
06-experiments/test07_5x5_grid/stl/caddy_feeder_print.stl
14.0 x 16.0 x 12.0

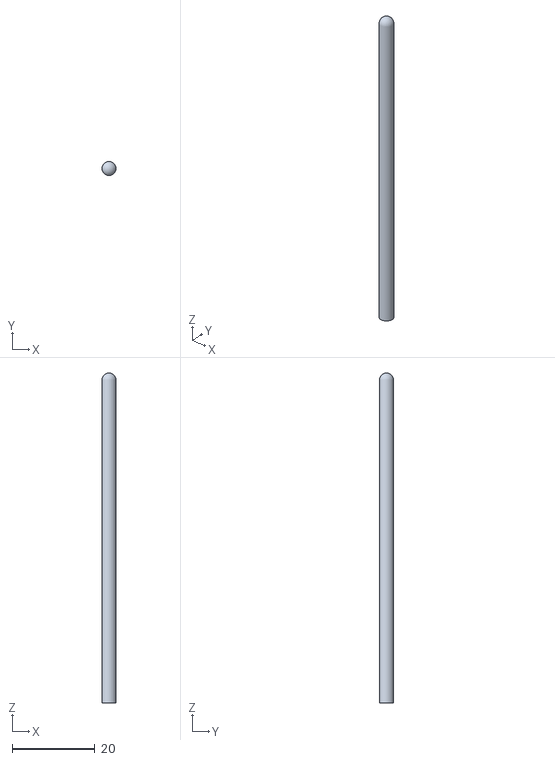
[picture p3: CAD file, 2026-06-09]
06-experiments/test06_sandwich_detent/push_rod.stl
3.40 x 3.40 x 80.0

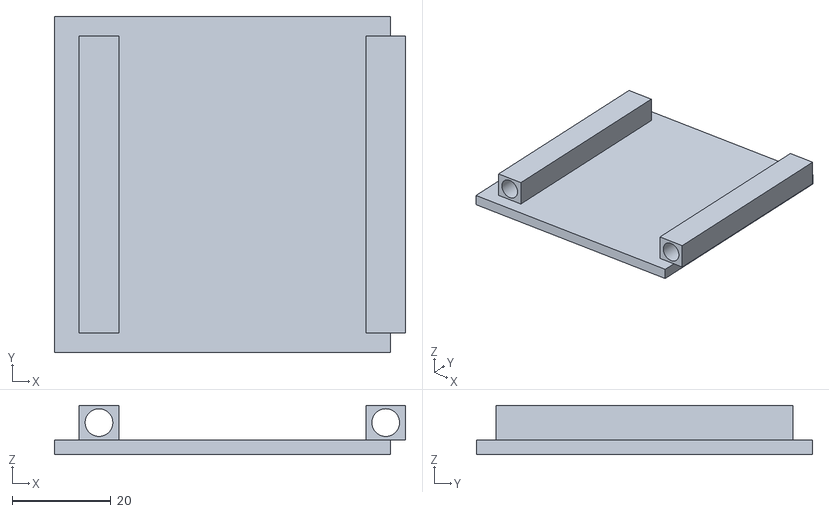
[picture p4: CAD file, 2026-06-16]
06-experiments/test07_5x5_grid/stl/caddy_base_print.stl
71.0 x 68.0 x 10.0

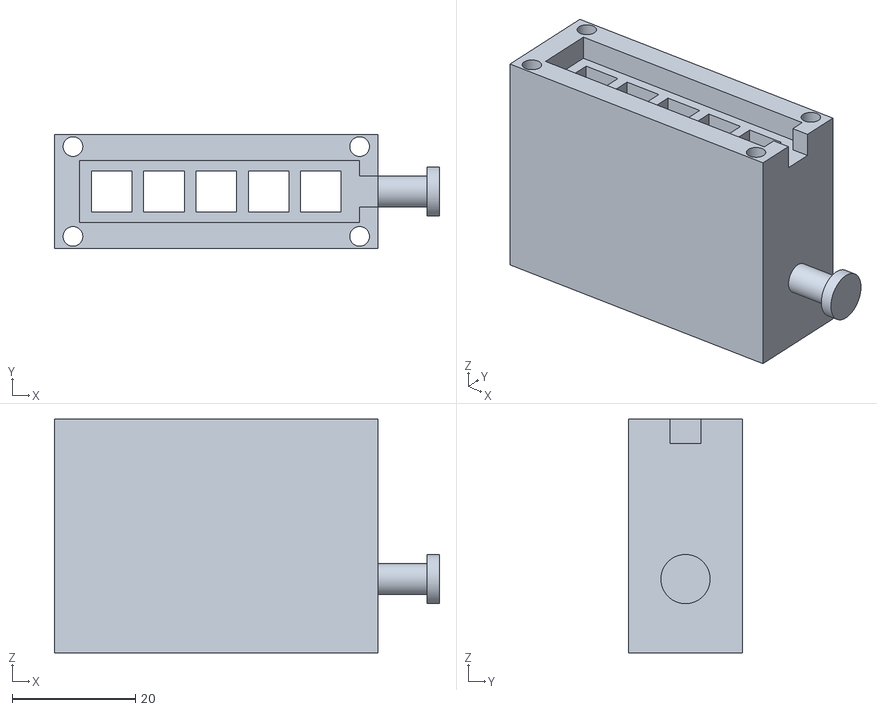
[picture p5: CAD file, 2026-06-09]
06-experiments/test06_sandwich_detent/grid_bottom.stl
62.6 x 18.6 x 38.0

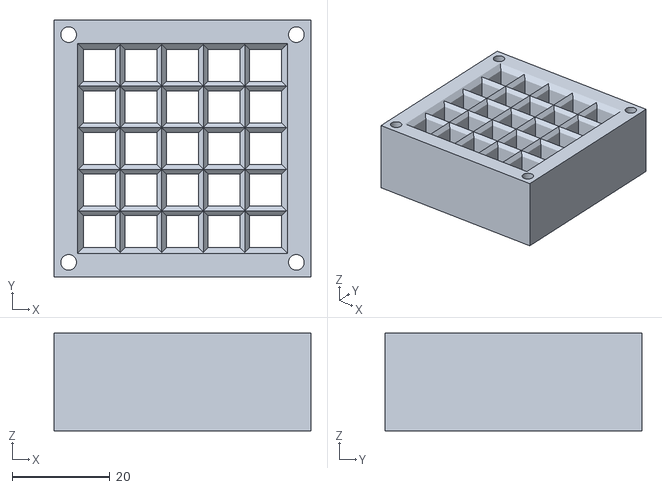
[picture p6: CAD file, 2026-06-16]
06-experiments/test07_5x5_grid/stl/grid_top.stl
52.6 x 52.6 x 20.0

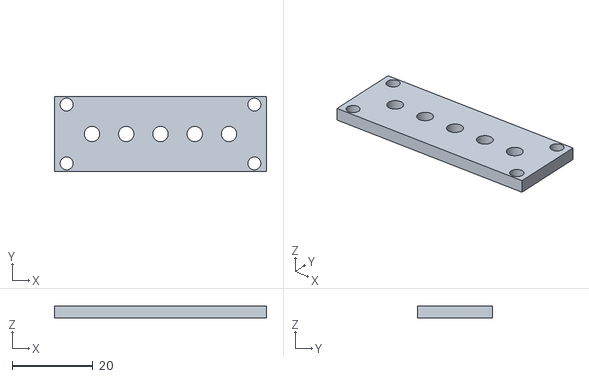
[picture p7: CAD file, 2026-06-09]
06-experiments/test06_sandwich_detent/floor_plate.stl
52.6 x 18.6 x 3.00

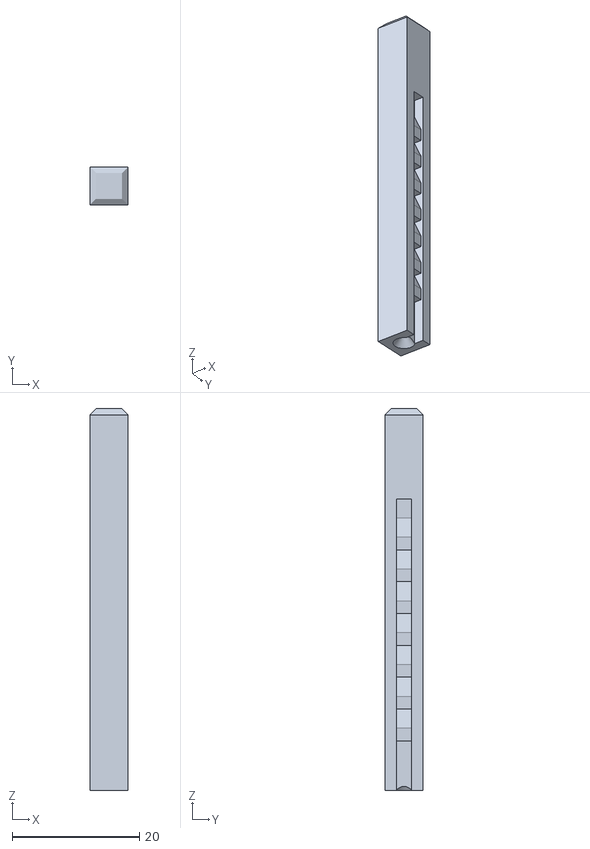
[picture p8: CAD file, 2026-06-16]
06-experiments/test07_5x5_grid/stl/pin.stl
6.00 x 6.00 x 60.0

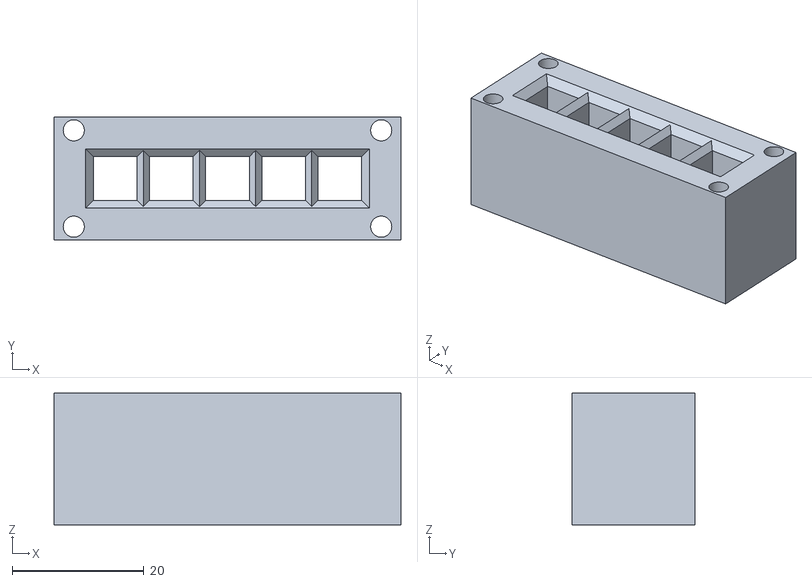
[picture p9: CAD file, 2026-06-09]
06-experiments/test06_sandwich_detent/grid_top.stl
52.6 x 18.6 x 20.0

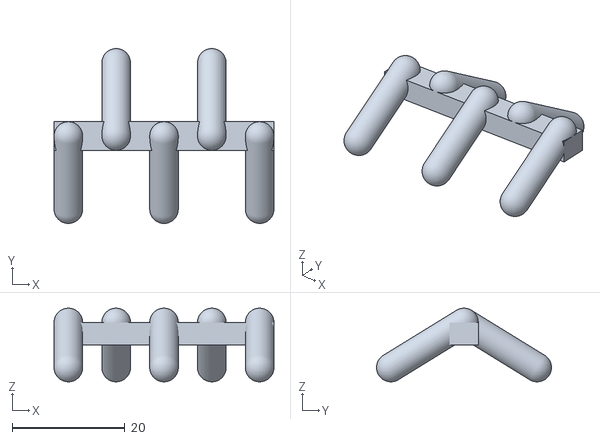
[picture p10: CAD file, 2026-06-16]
06-experiments/test07_5x5_grid/stl/caddy_tube_block.stl
39.1 x 31.1 x 13.1

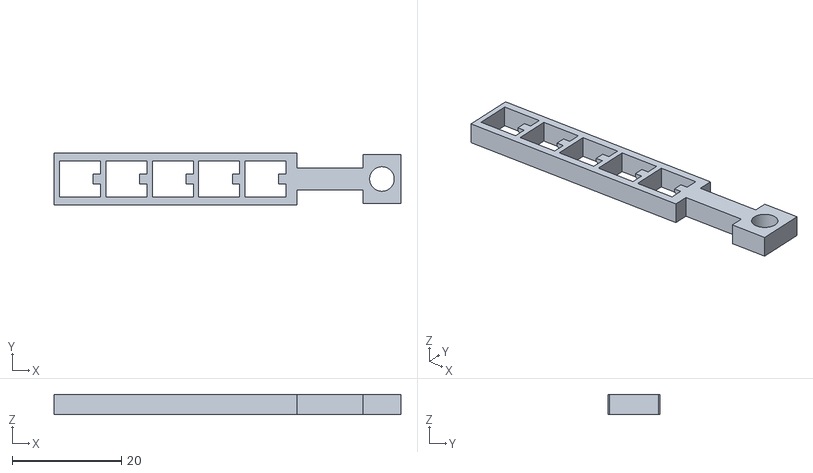
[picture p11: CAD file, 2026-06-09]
06-experiments/test06_sandwich_detent/release_strip.stl
63.5 x 9.60 x 3.70

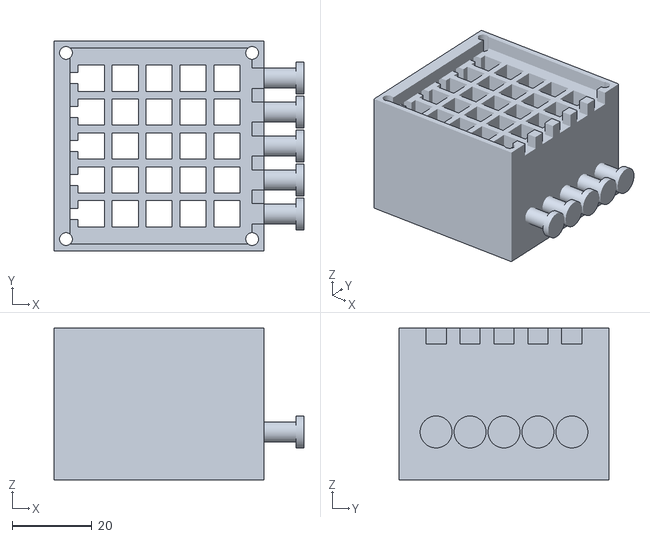
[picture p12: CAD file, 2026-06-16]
06-experiments/test07_5x5_grid/stl/grid_bottom.stl
62.6 x 52.6 x 38.0

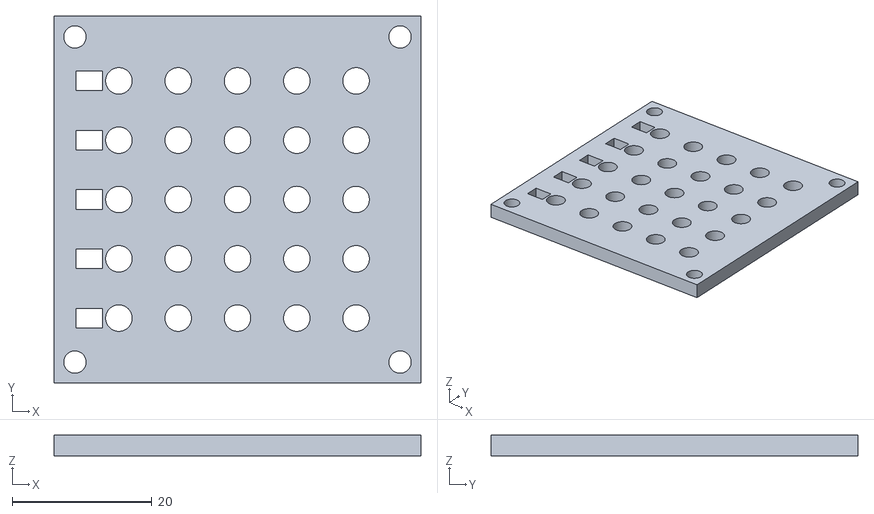
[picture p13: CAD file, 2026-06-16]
06-experiments/test07_5x5_grid/stl/floor_plate.stl
52.6 x 52.6 x 3.00

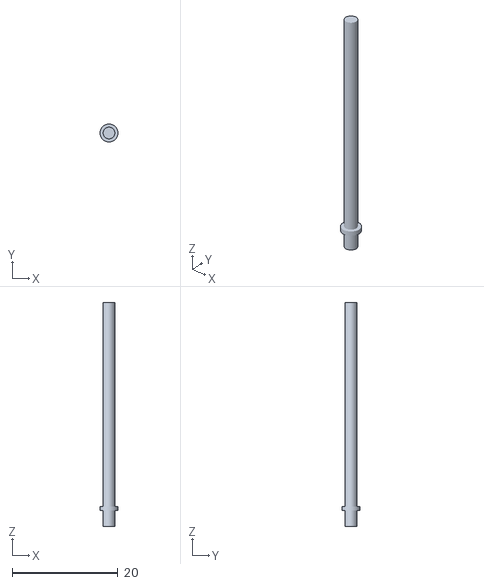
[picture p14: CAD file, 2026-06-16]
06-experiments/test07_5x5_grid/stl/release_dowel.stl
3.40 x 3.40 x 42.4

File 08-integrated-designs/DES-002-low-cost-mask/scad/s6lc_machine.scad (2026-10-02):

// design calculation S6-LC ultra-low-cost shape display -- real OpenSCAD geometry.
//
// EVIDENCE CLASS: CAD (geometry only). No print, no measurement (design calculation).
// All dimensions are mirrored from ../analysis/s6lc.py.
//
// Machine: 8 banks of 10 rows (80x80 = 6,400 cells) at 5.08 mm pitch.
//   * square printed columns with a 5-pocket vertical rack (10 mm pockets);
//   * printed cantilever pawls (0.90 x 1.20 x 8.00 mm) holding a column;
//   * per-bank threshold mask gate (printed sliding comb) read from a medium;
//   * 8 banked release combs on a travelling reset carriage;
//   * one 4-screw belt-synced platen (printed frame, excluded from the BOM).
//
// Render (real OpenSCAD):
//   openscad -o s6lc_cell.stl       -D 'PART="cell"'    s6lc_machine.scad
//   openscad -o s6lc_bank.stl       -D 'PART="bank"'    s6lc_machine.scad
//   openscad -o s6lc_platen.stl     -D 'PART="platen"'  s6lc_machine.scad

PART = "cell";

// ---- product / geometry constants (analysis/s6lc.py) ----------------------
PITCH       = 5.08;
BODY        = 3.60;      // square column body (S1 lane budget: 3.60 + 1.48 = 5.08)
COL_H       = 44.0;      // column height (40 mm travel + 4 mm base)
TRAVEL      = 40.0;
LEVEL       = 10.0;
POCKET_H    = 3.0;       // rack pocket depth in Z
POCKET_D    = 0.8;       // rack pocket depth in X (S1 coupon)
PAWL_T      = 0.90;      // 2 extrusion lines
PAWL_W      = 1.20;
PAWL_L      = 8.00;
ROWS_BANK   = 10;
COLS        = 80;
BANKS       = 8;

$fn = 48;

module column_with_rack() {
    // Square column body with 5 rack pockets on the +X face.
    difference() {
        translate([-BODY/2, -BODY/2, 0]) cube([BODY, BODY, COL_H]);
        // rack pockets at 0,10,20,30,40 mm above the base
        for (k = [0:4]) {
            translate([BODY/2 - POCKET_D, -BODY/2 + 0.4, 4 + k*LEVEL])
                cube([POCKET_D + 1, BODY - 0.8, POCKET_H]);
        }
    }
}

module pawl() {
    // Rooted cantilever: base block + thin leaf with a wedge toe.
    // design calculation/A1: the ROOT block is anchored OUTBOARD of the pitch band (in the
    // frame); only the thin LEAF (PAWL_T/2 = 0.45 mm) enters the owned 0.74 mm
    // lane. Leaf set back so its outer face stays <= 0.74 mm from the body edge.
    translate([0, 0, 0]) cube([PAWL_T, PAWL_W, 1.5]);          // root block (frame side)
    translate([PAWL_T - PAWL_T/2, 0, 1.5])
        cube([PAWL_T/2, PAWL_W, PAWL_L]);                       // thin leaf (enters lane)
    // toe wedge at the free end (points into the rack)
    translate([PAWL_T - PAWL_T/2, 0, 1.5 + PAWL_L - 1.2])
        multmatrix([[1,0,0,0],[0,1,0,0],[0.5,0,1,0],[0,0,0,1]])
            cube([PAWL_T/2, PAWL_W, 1.2]);
}

module mask_gate() {
    // Printed sliding comb: body bar + bosses over cells that must be BLOCKED.
    // One per bank (COLS = 80 cells wide); boss pitch = PITCH.
    bar_w = COLS * PITCH;
    translate([0, 0, 0]) cube([bar_w, 1.2, 1.0]);
    for (i = [0 : COLS-1]) {
        // alternating boss pattern is illustrative geometry; the real pattern
        // comes from the map. This renders the printable comb envelope.
        if (i % 2 == 0)
            translate([i*PITCH + PITCH/2 - 0.44, -0.4, 1.0])
                cube([0.88, 2.0, 1.2]);
    }
}

module release_comb() {
    // One bank release comb: a bar with a toe under every cell, lifted by the
    // travelling carriage to trip all pawls of the bank at reset.
    bar_w = COLS * PITCH;
    translate([0, 0, 0]) cube([bar_w, 1.2, 1.0]);
    for (i = [0 : COLS-1]) {
        translate([i*PITCH + PITCH/2 - 0.44, 0.8, 1.0])
            cube([0.88, 1.6, 1.0]);
    }
}

module bank_row() {
    // One row of a bank: 80 cells at true pitch, with pawl + gate lanes.
    for (i = [0 : COLS-1]) {
        translate([i*PITCH, 0, 0]) {
            column_with_rack();
        }
    }
    // pawl lane sits in the Y gap between rows (not rendered per cell here for
    // clarity of the row envelope; the cell module includes the pawl).
}

module cell_assembly() {
    // The unit-cell mechanism: column + pawl (side-by-side lane) + gate lane.
    // design calculation/A1: body edge at BODY/2 = 1.80 mm; owned lane runs to the half
    // pitch 2.54 mm. Place the pawl root so the LEAF outer face stays within
    // the half pitch: origin x0 = BODY/2 - (PAWL_T - PAWL_T/2).
    column_with_rack();
    translate([BODY/2 - (PAWL_T - PAWL_T/2), 0, 4]) pawl();
}

module bank_assembly() {
    // A bank: the full 80-column width at true pitch, rendered as 3
    // representative rows to keep the mesh tractable (the envelope width
    // 80 * PITCH = 406.4 mm is the printability-relevant dimension; the row
    // count does not change any gate). The real bank is 10 rows, sub-tiled.
    for (r = [0 : 2]) {
        translate([0, r*PITCH, 0]) bank_row();
    }
}

if (PART == "cell")     cell_assembly();
if (PART == "bank")     bank_assembly();
if (PART == "gate")     mask_gate();
if (PART == "comb")     release_comb();
if (PART == "platen")   cube([COLS*PITCH, ROWS_BANK*PITCH, 2.0]);

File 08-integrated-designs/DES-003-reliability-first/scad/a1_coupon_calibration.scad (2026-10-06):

// DES-003 / Q-009 critical-fit calibration coupon.
// Evidence class: CAD-derived/calculated only; no print or physical validation.
// Render: openscad -o a1_coupon_calibration.stl a1_coupon_calibration.scad
PITCH=5.08; BODY=3.60; CLEAR=0.20; LATCH_T=0.45; LATCH_W=1.20;
TRAVEL=40.0; FLAG_T=0.44; FLAG_W=1.60; FLAG_GAP=1.80;
SLIDE_W=8.0; SLIDE_L=42.0; SLIDE_H=6.0; SLIDE_RAIL=1.20; $fn=32;
OWNED_LANE=PITCH/2-BODY/2; HINGE_X=BODY/2+LATCH_T/2+CLEAR; FLAG_Z=TRAVEL+3.0;

// A: three actual binary-latch stations spanning the nominal clearance band.
module latch_station(c=CLEAR) {
  socket=BODY+2*c;
  difference(){ cube([14,14,3],center=true); translate([0,0,1.55]) cube([socket,socket,.4],center=true); }
  translate([0,0,23]) cube([BODY,BODY,46],center=true);
  translate([HINGE_X,0,1.5]) cube([LATCH_T,LATCH_W,3],center=true);
  for(z=[-TRAVEL/2,TRAVEL/2]) translate([HINGE_X,0,z]) cube([LATCH_T+2*c,LATCH_W+2*c,2],center=true);
  translate([HINGE_X,0,FLAG_Z-.4]) color("Gold") cube([FLAG_T,FLAG_W,.8],center=true);
  translate([HINGE_X,0,FLAG_Z+FLAG_GAP]) color("Orange",.35) cylinder(h=.2,d=FLAG_T+2*FLAG_GAP*tan(15),center=true);
}
module latch_band(){ for(i=[0:2]) translate([i*18-18,0,0]) latch_station(CLEAR+(i-1)*.1); }

// B: five true-pitch registration stations and half-pitch marks.
module registration_span(){
  translate([0,24,1.5]) cube([5*PITCH,8,3],center=true);
  for(i=[0:4]) { x=(i-2)*PITCH; translate([x,24,3.5]) cube([BODY,BODY,4],center=true); translate([x+PITCH/2,24,3.5]) cube([.44,BODY,4],center=true); }
}

// C: two-rail repeated-fit interface; clearance is intentionally adjustable.
module sliding_pair(c=CLEAR){
  difference(){ cube([SLIDE_L,SLIDE_W,SLIDE_H],center=true); for(y=[-SLIDE_W/2+SLIDE_RAIL/2,SLIDE_W/2-SLIDE_RAIL/2]) translate([0,y,0]) cube([SLIDE_L-4,SLIDE_RAIL+2*c,SLIDE_H+.2],center=true); }
  translate([0,0,SLIDE_H/2+1.5]) cube([SLIDE_L-8,SLIDE_W-2*SLIDE_RAIL-2*c,3],center=true);
}
module coupon(){ latch_band(); registration_span(); translate([0,-24,0]) sliding_pair(CLEAR); }
coupon();
echo(str("EVIDENCE=CAD-derived; physical_validation=unresolved"));
echo(str("PITCH=",PITCH," BODY=",BODY," CLEAR=",CLEAR," OWNED_LANE=",OWNED_LANE));
echo(str("LATCH_CLEAR_BAND=",CLEAR-.1,":",CLEAR+.1," FLAG_T=",FLAG_T));
echo(str("READER_FLAG_GAP=",FLAG_GAP," HALF_PITCH=",PITCH/2));
echo(str("SLIDE_CLEAR_BAND=",CLEAR-.1,":",CLEAR+.1," SLIDE_LENGTH=",SLIDE_L));

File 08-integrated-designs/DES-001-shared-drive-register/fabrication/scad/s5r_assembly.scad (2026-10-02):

// design calculation S5-R ASSEMBLED-SCENE library for board-viewable renders.
//
// This file places the printed part modules from `s5r_parts.scad` at their real
// relative positions so a render (or an STL) shows the ASSEMBLED mechanism, not
// the loose part set. It adds NO new part geometry: every solid is the same
// module the printable STLs are rendered from, so an assembly image is true to
// the shipped geometry.
//
// Two scenes are exposed via `scene=`:
//   * "cell_cluster" -- a 3x3 cartridge tile with rotors, pawls, keepers and
//     detent leaves installed in every cell, a rack strip + sourced steel rod
//     in the centre row, i.e. the per-cell register as it sits in the field.
//   * "cell_exploded" -- the same cluster with the moving parts lifted +Z and
//     the rack/rod pulled +Y, so the cell, rotor, pawl, keeper, detent and rack
//     stack is readable.
//
// EVIDENCE CLASS: CAD assembly geometry. NOT a printed or measured assembly
// ([design calculation]). The sourced steel rod is shown as a bare cylinder for context; it
// is not a printed part.

include <s5r_parts.scad>

// --- placement (mm), mirrored from `s5r_parts_common.scad` ----------------
ASSY_COLS = 3;
ASSY_ROWS = 3;

// cell centre (x,y) of cell (cx,cy) in an ASSY_COLS x ASSY_ROWS tile
function cell_x(cx) = (cx - (ASSY_COLS - 1) / 2) * PITCH;
function cell_y(cy) = (cy - (ASSY_ROWS - 1) / 2) * PITCH;

// The cartridge part subtracts `inner_cell()` (rotor bore + pawl chamber +X +
// keeper chamber +Y) at each cell centre, all rooted at z = 0 = housing top.
// Rotor sits in the bore (z 0..CELL_H); pawl chamber is +X; keeper chamber +Y.

module rotor_at(cx, cy, dz = 0) {
    translate([cell_x(cx), cell_y(cy), dz]) rotor();
}

module pawl_at(cx, cy, dz = 0) {
    // pawl chamber is +X of the bore; leaf hangs down the chamber at z 0..LEN
    translate([cell_x(cx) + PAWL_T / 2, cell_y(cy), dz]) drive_pawl();
}

module keeper_at(cx, cy, dz = 0) {
    // keeper chamber is +Y of the bore
    translate([cell_x(cx), cell_y(cy) + KEEPER_T / 2, dz]) keeper();
}

module detent_at(cx, cy, dz = 0) {
    // detent leaf rides the -X wall of the bore, scallop toward the rotor
    translate([cell_x(cx) - WALL, cell_y(cy), dz]) detent_leaf();
}

// The cartridge tile itself: real printed geometry (true 27x27 module supports
// cols/rows), rendered here at the small ASSY tile size for a readable scene.
module cartridge_tile() {
    cell_cartridge(ASSY_COLS, ASSY_ROWS);
}

// One full populated cell (rotor + pawl + keeper + detent).
module populated_cell(cx, cy, dz = 0) {
    rotor_at(cx, cy, dz);
    pawl_at(cx, cy, dz);
    keeper_at(cx, cy, dz);
    detent_at(cx, cy, dz);
}

// Sourced steel rod (NOT printed): a plain Ø6 mm cylinder through the rack
// channel under the centre row, drawn short so it reads as a drive rod.
module sourced_rod(len = ASSY_ROWS * PITCH + 24) {
    // rack channel centre is at y = 0 for the centre row, just under the tile
    translate([-len / 2, 0, -BAR_D - 0.0])
        rotate([0, 90, 0]) cylinder(r = BAR_D / 2, h = len);
}

// A printed rack strip for the centre row, teeth up, clipped on the rod.
module centre_rack() {
    translate([-(ASSY_COLS * PITCH) / 2, -RACK_STRIP_W / 2, -BAR_D - 0.0]) rack_strip(ASSY_COLS * PITCH);
}

module cell_cluster() {
    cartridge_tile();
    for (cx = [0 : ASSY_COLS - 1], cy = [0 : ASSY_ROWS - 1])
        populated_cell(cx, cy);
    centre_rack();
    sourced_rod();
}

module cell_exploded() {
    cartridge_tile();
    // rotors + register lifted clear of their bores
    for (cx = [0 : ASSY_COLS - 1], cy = [0 : ASSY_ROWS - 1])
        populated_cell(cx, cy, dz = CELL_H + 6.0);
    // rack + rod pulled down/clear
    translate([0, 0, -10.0]) centre_rack();
    translate([0, 0, -18.0]) sourced_rod();
}

scene = "cell_cluster";

if (scene == "cell_cluster")        cell_cluster();
else if (scene == "cell_exploded")  cell_exploded();

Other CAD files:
06-experiments/test07_5x5_grid/stl/release_strip.stl
08-integrated-designs/DES-001-shared-drive-register/fabrication/scad/s5r_parts.scad
06-experiments/E-018-four-plane-mask-generator-coupon-package/cad/four_plane_mask_coupon.scad
06-experiments/test01_threaded_rods/bolt-v1.scad
06-experiments/test01_threaded_rods/bolt-v2.scad
06-experiments/test01_threaded_rods/bolt-v3.scad
06-experiments/test01_threaded_rods/cube-v1.scad
06-experiments/test01_threaded_rods/cube-v2.scad
06-experiments/test03_threaded_rod_actuator/actuator.scad
06-experiments/test03_threaded_rod_actuator/calibrate_rect_tube.scad
06-experiments/test03_threaded_rod_actuator/calibrate_screw.scad
06-experiments/test03_threaded_rod_actuator/frame-body.scad
06-experiments/test03_threaded_rod_actuator/frame-plank.scad
06-experiments/test04_plain_cubes/cube.scad
06-experiments/test04_plain_cubes/frame.scad
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

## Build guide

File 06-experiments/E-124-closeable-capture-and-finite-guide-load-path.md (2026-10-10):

---
status: complete
builds-on: [E-123, E-115]
---

# Remote guide play defeats the nominal side shoe; balanced capture changes the load path

**Stop treating E-123's face-error pass as a guided-head pass. Retain a bilateral
lower-entry cup as a changed capture interface for powered-joint investigation.**
A finite tilted-body witness intersects the E-123 web and foot by **.439998 mm³**
at e=.05 and guide centre half-play c=.025 mm. A cup can acquire from below and
place opposing upper contacts around a narrower foot without the side shoe's
nominal eccentric load. Neither is a completed powered head: cup jaw retention,
actuators, ground-lock access, proof and fault recovery remain unimplemented.
No machine, timing/cost survivor, fabrication or purchase is admitted.

Input main `b8843b9`. Reproduce:

```
python3 tools/curated-experiment-checks/E-124/capture.py
```

Evidence: deterministic generated box solids, continuous axis sweeps, finite
rotated-polygon intersection, analytical guide/elastic enclosures and numerical
integration self-checks. No random distributions, process measurements, sourced
material allowables, calibrated friction, CAD release or physical qualification.
Output JSON is reproducible and not retained. This resolves a distinct
capture/guidance question within the direct-head campaign, not its power/lock
completion gate. Existing pad-lowering, compact e=.10 packing and closed-guide
rack-crossing failures remain executable checks from E-123.

## Finite guides and correlated pose errors

Column guide stations are centred at z=45 and 75 mm; travelling-head shaft guide
stations at z=−10 and −40 mm. Each modelled sleeve has four .8-mm walls and a
2-mm axial length, around the rectangular shaft plus clearance. The code checks
upper-sleeve packaging against the nominal column and full capture sweep. The
lower shaft's actual powered construction remains absent; its stations define a
beam/pose scenario, not a packaged actuator. Both pairs span S=30 mm.

`c` is remaining centre half-play **after** form, alignment, projected shaft
width and finite sleeve length have been allowed. It is not a specified hole
dimension or an assertion that X1C delivers that fit. For a foot at h=0…40,
column overhang Lc=45−h and head overhang Lh=h+10 give extremal centre excursions

`dc=c(1+2Lc/S), dh=c(1+2Lh/S)`.

The two overhangs belong to the same height: their sum is 55 mm, so
`dc+dh=5.666667c` throughout travel. Taking both longest overhangs simultaneously
would exaggerate the result. Opposite contacts at each guide's endpoints realise
these pose bounds. Nominal stations plus an unspecified zero-clearance shaft do
not establish a guide. Sleeve overlap, contact force and bind/wear remain gates.

An additional rotation enclosure uses `theta=atan(2c/S)` and local vertex radii
3 mm for the foot and 6 mm for the head. E-123's independent translation/face
errors still contribute 4e. The capture clearance screen therefore uses

`d=4e+5.666667c+18 sin(theta/2)`.

The head-to-head check separately doubles the worst head excursion and rotation;
neighbouring outputs need not share a height. Common rigid translation cancels;
coherent adverse guide tilt, batch size bias and spatial warp need not cancel.
These are bounded epistemic scenarios, not yield estimates. Residual warp is
charged separately below; no independent-cell probability is used.

For the original C shoe, set c=.025, e=.05, h=0. The head centre extrapolates
+.041667 mm and the column −.100000 mm. Give both their compatible +.001666665-rad
tilt and E-123's adverse opposing faces. Clipping actual rotated web and foot
polygons gives **.439998 mm³** intersection, versus .440000 mm³ in the parallel-axis
limit. This is an actual failure corner, not rejection merely because an
uncertainty enclosure overlaps. The c scenario is not a measured process floor;
it invalidates an unconditional pass, not every precision guide.

## Changed capture: bilateral cup from below

The geometric witness replaces the 4×2.8-mm foot with **2×2.8×1.2 mm**, on a
1.2×1.2-mm stem. Surface pitch remains 5.08 mm; the top cap is unchanged in the
product interface and is not generated here. A centred lower pad sits on a
pedestal/base. Two lateral webs carry upper contact pads; each pad can move over
the foot shoulder and then take up vertical play. Finite channel walls locate
the lower sliding parts. **The upper pads' positive retention, all drives and
channel fit/anti-lift retention are not implemented.** Prescribed pad coordinates
are only a contact-interface screen and cannot carry a claimed tensile load.

Open envelope is **4.4×2.8 mm**. Each horizontal closing stroke is .4 mm; vertical
upper-pad take-up is .4 mm nominal. Approach with the jaws open from below the
old foot; reach lower-pad contact; close laterally above the foot; then take up
the upper clearance. The two upper pads and lower pad touch the nominal foot
with zero slot play. Release reverses these steps only after an independently
proved ground support, which is an obligation, not implemented logic. Positive
powered take-up would need sufficient travel for actual face errors, preload,
nonparallel faces and wear, plus a retained stop/power-loss path.

Unlike a side shoe, this route approaches with its upper fingers outside the foot
and brings contacts over **both** shoulders. A symmetric realised contact force
could centre the load on the stem. Symmetric CAD alone does not balance forces:
unequal seating, warp, sliding friction and preload can restore eccentricity.
The unresolved coupled contact model must determine the actual load distribution.

Continuous swept boxes check the open approach, lateral closing and vertical
take-up against the own column. Every neighbour's height is independently swept
through 0…40; separated head hulls bound adjacent heads at different heights.
The closed interface is checked at all 81 indexed old/target pairs in the
holdout; common translation extends the same geometry continuously. This does
**not** prove an unlocked supported transaction, a loaded motion or fault safety.

Generate foot width {2,2.1,2.4,2.8}, stem 1.2, overlap/back/entry each
{.2,.225,.3,.4}, and web {.6,.8}: **512 sections per scenario**, one new capture
topology. The .025-mm reserve is inherited as a screen, not a qualified fit.

| e mm | c mm | Cup contact sections passing /512 |
|---:|---:|---:|
| .025 | 0 | 78 |
| .025 | .005 | 60 |
| .025 | .025 or .05 | 0 |
| .05 | 0 | 3 |
| .05 | .005, .025 or .05 | 0 |
| .10 | 0, .005, .025 or .05 | 0 |

Zero-play rows are mathematical limits. Counts are contact-section screens plus nominal finite sweeps, not complete
uncertain-geometry or drive/joint-retention admission. Grid/enclosure failures do not prove that every bilateral cup fails.
The witness at e=.025,c=.005 has .068667-mm entry/web/stem/overlap margins,
.532667 mm between head hulls and .297 mm vertical entry clearance. Only
**.043667 mm** remains beyond the chosen reserve for additional relative warp,
load-related pose mismatch and model discrepancy. Tightening a nominal hole does
not establish that allowance in a full bank.

For comparison, allocating a **2-mm side-spine housing** for a hypothetical
1.2-mm screw plus surrounding structure replaces E-123's .6-mm web. Applying
its eliminated section inequalities to the expanded pose enclosure requires
4.450667-mm pitch at e=.025,c=.005, but 5.250667 mm at e=.05,c=.005. This is a
conservative housing screen, **not a generated screw/nut, a proof of universal
impossibility, or a complete retained clamp**. Power cannot be assigned free
space inside the original thin web.

## Eccentric load, warp and the next fidelity gate

For a beam with two lateral simple supports S apart, an overhang L and an end
moment M, integrating Euler–Bernoulli curvature gives

`tip displacement=M(L²/2+SL/3)/(EI)`,
`tip rotation=M(L+S/3)/(EI)`.

Units are N, mm and N/mm². The code separately integrates curvature through both
supported span and overhang at 16/64/256 steps, enforcing zero displacement at
both bearings. Zero moment and inverse-modulus limits also agree. This is a
linear elastic scenario; values beyond .5-mm displacement are flagged outside
the chosen small-deflection screen and are not quantitative hardware predictions.
Buckling, shear, creep, frictional support, anisotropy and joint compliance are
not resolved by this check.

Side scenario: column I=.2304 mm⁴, screw-housing spine I=2.564879 mm⁴ after
subtracting a 1.2-mm round bore, force eccentricities .95/1.35 mm at column/head.
Balanced scenario: column I=.1728 mm⁴, a 2×2-mm lower shaft I=1.333333 mm⁴ and
**assumed residual eccentricities .05 mm** at each. Moduli {500,2000,100000}
N/mm² and forces {.06,.1,1,10} N are deliberately labelled alternatives, not
PLA/metal specifications or allowable stresses. End heights bound the convex
sum of the two responses, without mixing incompatible head/column heights.

At E=2000 and F=.06 N, summed magnitudes of **free** tip response are .183277 mm
for the side route versus .012864 mm for the balanced residual scenario. At
.1 N they are .305461/.021440 mm. A closed jaw cannot simply separate by these
amounts: it reacts the incompatibility through lateral force/moment and guide
contacts. Therefore these numbers prioritize a **coupled beam/contact solve**;
they are neither actual closed-head displacement nor binding/strength acceptance.

E-123's 5-g mass and .060-N drag require .109050 N upward at zero acceleration,
or .134050 N at 5 m/s². For the balanced residual scenario, the free-response
screen consumes .023380/.028740 mm, leaving .020286/.014926 mm of the geometric
reserve budget. Adding an explicit .025-mm relative warp bound exceeds that
budget by .004714/.010074 mm. This is a failed reduced-model budget, not a proved
physical jam. Zero warp fits this budget but earns no powered-head pass.

**Continue the existing task:** implement retained upper jaws and actual power
transmission with their finite routing; solve coupled contact/guide reactions
including preload asymmetry before accepting controlled lowering. Include a
positive ground-bolt set/reset path and physical output proof, common readback
errors, safe stop and recovery through the entire transaction. Do not advance
system timing/affordability from these partial interface counts. Stop the present
compact side housing if its loaded/retained implementation cannot fit; allow
changed internal pitch, relocated guides or a genuinely changed capture route.
No print is justified before those computational completeness gates.

Self-review only: exact sweep and polygon limiting cases, correlated guide
corners through all 41 integer heights, continuous-height envelope, all admitted
nominal interface sweeps, refined acquisition holdouts and independent curvature
integration. No independent review or physical evidence is claimed.

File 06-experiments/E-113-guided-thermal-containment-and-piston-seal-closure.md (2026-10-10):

---
status: complete
builds-on: [E-112, A-018]
---

# Park the side-bay thermal strut after supported containment closure

Input main `aac9fff`. **Park these short-stroke thermal-strut embodiments.**
Guided rolling and sliding-seal packages close a conditional liquid cycle but
exceed the inherited side bay once roof/duct and return are included. Neither
establishes a repeated process or cost advantage over a dry mechanical stop.
This excludes the studied implementations, not thermal support in general.
No thermal optimization, fabrication or procurement follows.

Reproduce: `python3 tools/curated-experiment-checks/E-113/containment.py`.
Two topologies; deterministic bounds, no random seed. Units: mm, N, MPa, s.
Evidence: analytical geometry, reduced quasistatic calculations and sources;
no measurements, nonlinear film/contact solution or hardware qualification.

## Guided boundary, finite duct and return

E-112 puts liquid **below** its U. Positive pressure pushes the inner leg away
from an ordinary inner piston and the outer leg away from an outer bore.
Those supports cannot simply be appended to that liquid domain. Generate liquid
**above** the U, under roof `T=S/2+h`, h=.2. Retain b=a+2ρ, ρ=.2,
`zc=(q−S/2−.2)/2`, `−S/2≤q≤S/2`. The dry t=.05 offset has radius ρ+t,
inner radius a−t and outer radius b+t. A piston `r≤a−t` extends below the entire
fold sweep; a bore `r≥b+t` backs the outer leg. Positive pressure seats both.
The free fold still needs tensile/bending equilibrium; circular geometry and
constant thickness are not a constitutive solution or a pressure-stability pass.

Liquid volume and effective area are
`V=πb²T−πa²q−π(b²−a²)zc+π²(a+ρ)ρ²`, `dV/dq=−A`,
`A=π(a²+b²)/2`. The frozen core spans head to grounded roof, minimum gap .2;
head film is compression-loaded between them. Jaw guides carry vertical load.
At assumed H=10 tan30°=5.774 and effective solid stress σ=5, use
`am=sqrt(H/(πσ))+t+2e`, `ar=sqrt(H/(πσ))+t` for adverse opposite-radius errors.
σ is a whole-strut hypothesis, not an alloy strength or creep allowable.

Capsules have parallel horizontal axes at separate depth levels, fixed roofs
aligned, center separation D=outer diameter+.4. Generate a roof channel .8 wide,
hd=.2−e high, centered .3+hd/2 beyond each chamber roof. Two end ports connect
the channel to the chamber centers; moving boundaries never cross them.
The exact union volume of channel and overlapping rectangular ports is
`.8 hd(D+.6+hd)`. Roof allowance is .3+nominal .2+.3 cover=.8, replacing the
old unplumbed .3 wall. Body span includes deepest fold, .1 dry clearance and
this roof. Heater, insulation, attachment corners and seats remain additional.

Free reservoir travel accepts main stroke s=.45+e and both signs of ±ηV:
`Sr=(Am s+2ηV)/Ar`. Since Vr(Sr) is affine with slope Kr, solve
`Sr=[Am s+2η(Vm(s)+Vr(0)+Vduct)]/[Ar−2ηKr]`; reject nonpositive denominator.
This closes **liquid** inventory, not volume accommodation through a frozen duct.

A dry coaxial spring behind the reservoir transfers preload to ground: .08 wire,
.8 mean diameter, eight active/two inactive turns, assumed G=70,000.
`k=Gd⁴/(8D³n)=.0875 N/mm`; installed minimum length .9 leaves .1 above solid
height; maximum length .9+Sr; free length adds .03/k for .03-N preload.
It is an explicit candidate, not a qualified spring. Reservoir pressure is
`pr=(.03+kx)/Ar`, x travel from minimum-force endpoint. Virtual work independently
checks `Fm=pm Am` against reservoir spring work with area-ratio displacement.

## Different encapsulation: sliding seals

Replace films with piston O-rings and finished bores. A deliberately optimistic
custom .7 seal section, 15% radial squeeze, .15 core-to-groove ligament,
groove width 1.3 sections and .2 end lands gives piston radius
`sqrt(H/(πσ))+.15+.85(.7)` before error. This is not a catalog-qualified seal.
Liquid is `A(h+S/2−q)`; the swept seal band stays below the roof ports.
The same generated duct, accommodation and return apply. Hoop cycling disappears,
but breakaway, wear, alloy compatibility and precision bore manufacture enter.

At net gland error .05, squeeze spans 7.9–22.1%; at .15, −6.4–36.4%, including
lost interference. These are bounded scenarios, not X1C accuracy predictions.
With seal drag f, `(Fspring−f)/Ar≤pr≤(Fspring+f)/Ar`; increasing preload by f
preserves minimum pressure. f=0/.03/.3 are assumed bounds. The .3 case requires
about 1,779-MPa coil shear by the Wahl correction: different spring geometry
or evidence is needed. Even the rolling .05 case's 491-MPa coil stress has no
qualified fatigue margin. Bore finish, ovality, swelling and pressure extrusion
remain outside this model; printed layer resolution establishes none of them.

## Packing, equilibrium and failure results

E-112's centered 1-mm rack and .15 clearance leave a **1.89-mm axial side bay**.
Bodies and installed reservoir springs are end to end; no nesting, remote
preload or force-turning linkage is silently credited.

| Route / e | Sr | Inventory mm³ | Bare body | Body + spring | Bay overrun |
|---|---:|---:|---:|---:|---:|
| Rolling / 0 | .687 | 5.755 | 2.137 | 3.724 | 1.834 |
| Rolling / .05 | .889 | 6.598 | 2.339 | 4.128 | 2.238 |
| Rolling / .15 | 1.430 | 8.781 | 2.880 | 5.210 | 3.320 |
| Sliding / 0 | .553 | 5.891 | 2.863 | 4.315 | 2.425 |
| Sliding / .05 | .693 | 6.671 | 3.003 | 4.596 | 2.706 |
| Sliding / .15 | 1.046 | 8.630 | 3.356 | 5.303 | 3.413 |

All six packages fail this placement even without the spring. At e=.05,
η=0→.1 changes rolling Sr .617→1.224 and inventory 5.976→7.365; zero excursion
does not rescue body+spring. Rolling hoop cycle excursion is still 53.3% at the
middle case. Eccentricity .05/.15 is 10/30% of the .5 hardware convolution width.
These errors can repeat across a batch; there is no IID-cell yield inference.

For .5-s transfer, rectangular-duct Stokes flow with sidewall correction gives
`pm=pr±Δp`. Include straight port lengths; omit bend losses optimistically.
At e=.05, viscosity .002/.02/1 Pa·s gives Δp .000126/.001258/.06291 for rolling
and .000310/.003103/.15515 for sliding. Their minimum reservoir pressures are
.01235/.00523; thus the 1-Pa·s return has negative **gauge** main pressure.
This violates intended positive backing/return, not a prediction of cavitation
at that exact pressure. Higher preload or slower flow trades force/stress/time.
At e=.15 rolling loses positive return at .02 Pa·s, sliding even at .002.
Partial freeze, debris and non-Newtonian behavior invalidate the fully molten
calculation; these viscosity bounds are not material data or probabilities.

Melting before collet unloading requires 1.9255-MPa rolling main pressure.
Spring equilibrium extrapolates to 53.1-mm reservoir motion versus .889 allowed:
**the travel stop is reached**, not 53-mm physical travel. Sliding also reaches
its stop. Preload cannot support service load. Keep collet support through
melt/move/refill/freeze/proof and provide a separate catch for heater faults.
Stop contact does not establish seal pressure capacity.

If the roof duct freezes first, reservoir movement cannot relieve the chamber.
Constraining assumed 5% volume change at competing bulk-modulus bounds .1–30 GPa
would require elastic pressure 5–1,500 MPa. These are not alloy properties or
actual pressures: yielding, film expansion, cracks or voids intervene. A reopened
capsule must establish freeze sequence and sustained core creep; liquid-volume
closure and temperature readback cannot prove a solid load path.

Mechanical comparator: a grounded rectangular crossbolt holds the same sloped
jaw's H. A 1×1 contact/shear section requires nominal 5.774-MPa stress before
bending/concentrations. Collet unloads; bolt withdraws 1.15 in depth to clear a
1-mm-high jaw by .15; jaw withdraws .5. Reverse, seat and proof unload. Generated
intervals confirm bolt/jaw separation. The dry stop needs reset/addressing,
bearing/guide qualification and repair access, but no liquid boundaries, charge,
duct or freeze inspection. No complete-machine win is asserted; thermal
containment has not justified its extra burden against this simpler control.

## Material, process and repeated burden

Primary sources, accessed 2026-10-10:

- [Bellofram manual](https://damapi.marshbellofram.com/uploads/Bellofram_Diaphragm_Design_Manual_2022_7a922642c3.pdf), pp. 3, 24–25: pressure-side orientation, reversal damage and eccentricity guidance support backing/alignment requirements. They do not qualify our 50-μm film, alloy exposure or cycling. Its area formula remains different from the prescribed circular geometry (E-112).
- [Parker handbook](https://www.parker.com/content/dam/Parker-com/Literature/Praedifa/Catalogs/Catalog_O-Ring-Handbook_PTD5705-EN.pdf), table 2.8: hydraulic reciprocating contact Ra .40 μm, Rmax 1.60 μm. This is process guidance, not printed-PLA capability or molten-alloy seal compatibility.
- [Lussi et al., 2021](https://pmc.ncbi.nlm.nih.gov/articles/PMC8456283/), fabrication/material sections: a submillimeter catheter uses 150-μm UV-cured PFPE, custom heated aluminum microchannel molding and Cerrolow 117 containing lead/cadmium. Micro-encapsulation evidence does not transfer to rolling/sliding lifetime, creep or economical array manufacture.
- [RotoMetals](https://www.rotometals.com/roto-blog/fields-metal-from-scientific-oddity-to-essential-lowtemp-workhorse/): Roto144F is Bi/In/Sn, nominally 62°C. Its different chemistry/temperature prevents importing the catheter compatibility result. No retrieved source establishes the proposed pair's 5-MPa long-term creep, seal compatibility or film life.

Rolling requires preformed film, clamp/bond interfaces, aligned piston/bore,
sealed roof layers, filling/degas and inspection; sliding substitutes grooves,
finished bores and compatible lubrication. Neither is a thin-FDM-film process.
PLA guides/walls retain unqualified thermal creep, warp, anisotropy and fit.
No material-life distribution is invented from dimensions or tensile data.

Both routes repeat 12,800 moving boundaries, 6,400 charges/return paths/preloads,
heaters/switches and jaw/proof interfaces. Two attachments per film boundary can
mean 25,600 sealing lines. At shared reserve $150/$250/$350, the residual under
$500 is <$0.02734/$0.01953/$0.01172 per boundary **if all other site parts are
free**; no quote supports it. Assumed 5/15/30-second handling per boundary alone
means 17.8/53.3/106.7 hours before manufacture, charging, inspection and repair.
Integrated sheets could change this, but are a process hypothesis, not savings.
Batch swelling, clamp creep or shared heating can fail a module together.
Replacement requires a supported pin and preserved neighbors; no service design
or false-accept readback model is qualified by this local calculation.

## Disposition and checks

Stop these side-bay embodiments; keep A-018 a bounded family. Reopen only with
changed placement/return **and** a plausible compatible repeated process, or new
components altering these bounds. Smaller radii and ideal seals are insufficient.
This closes LAB-207's finite-containment gate without a thermal survivor; do not
start its dependent thermal/full-machine tasks. Next portfolio gate: identify a
materially different complete thermal architecture escaping inventory/process
failures, or conclude the campaign and redirect toward passive positive support
and shared addressing. Preserve the administrative recovery guard.

Self-review: independent radial integration at 128/512/2048 slices gives maximum
errors .00018316/.00002291/.000002865 mm³ on two off-grid cases. Complementary
volumes check the liquid-side change. 101-state dry-surface checks verify backing
envelopes/roof gap; monotonic bounds cover intermediate states. Both volume
excursion signs close over 101 main positions. Work/area ratios, spring-energy
integration, linear viscosity scaling, parallel-plate bound, closed duct, bolt
clearance and liquid-load stop failure are checked. This verifies reduced
necessary conditions, not nonlinear pressure stability, freeze mechanics or
hardware durability. No independent external review occurred.

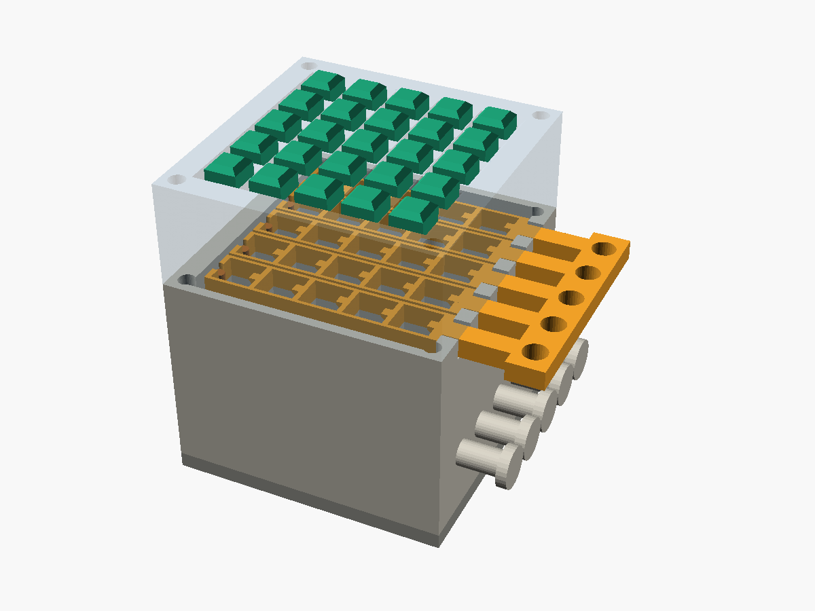
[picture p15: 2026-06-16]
06-experiments/test07_5x5_grid/assembly_released.png

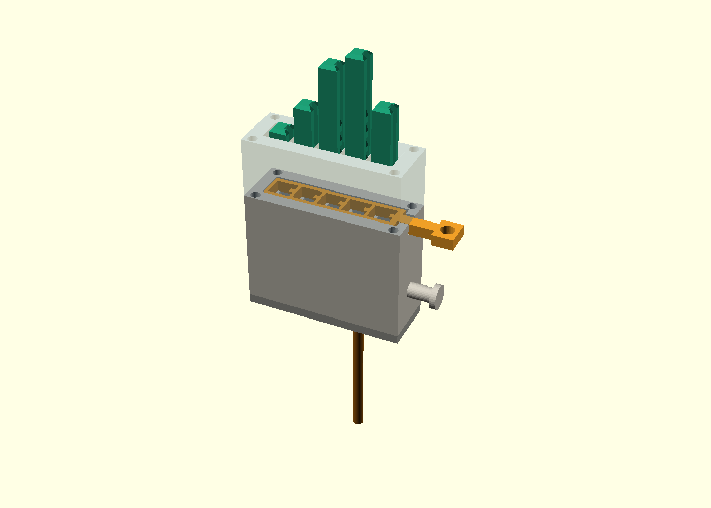
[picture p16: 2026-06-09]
06-experiments/test06_sandwich_detent/assembly.png

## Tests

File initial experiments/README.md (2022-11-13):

# Shape display

# Resolution

must be even number x even number

## Grid
--------------------→ x-axis
| (0,0) (1,0) (2,0)
| (0,1) (1,1) (2,1)
| (0,2) (1,2) (2,2)
|
↓
y-axis

## Primary and secondary holes.
Every cell in the grid contains a primary hole and optionally a secondary hole.
A cell with only a primary hole will only let air pass if its filter layer shifts to the correct position.
A cell with both a primary and secondary hole will always let air pass, irrespective of filter layer shifts.

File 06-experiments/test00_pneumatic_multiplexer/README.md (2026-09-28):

# Legacy test — pneumatic multiplexer

This is a **legacy test** preserved as historical design evidence. It predates
the current suggested testing framework and does not need to be migrated to it.

The experiment explores a SolidPython-based pneumatic multiplexer shape-display
concept and retains its original source, requirements, renders, and local
documentation. Its original language, API, and file layout are intentionally
allowed to remain as-is.

## stepper motor
Generic micro stepper motor from [Aliexpress](https://nl.aliexpress.com/item/4000806393169.html) at €0.52 per pair (see also listing on [Amazon](https://www.amazon.com/Abovehill-Stepper-2-Phase-4-Wire-Connection/dp/B08346RFVZ)).

| specifications | |
|-----|---|
| wiring | two phases, four wires|
| resistance | 40 Ω |
| recommended voltage | 5-6V |
| driving current | 0.12A |
| short-circuit current | 0.14A |
| connection lines 1 | blue: A +, black: A-, red: B+, white: B- |
| connection lines 2 | purple: A +, yellow: B-, orange: B+, green: B- |

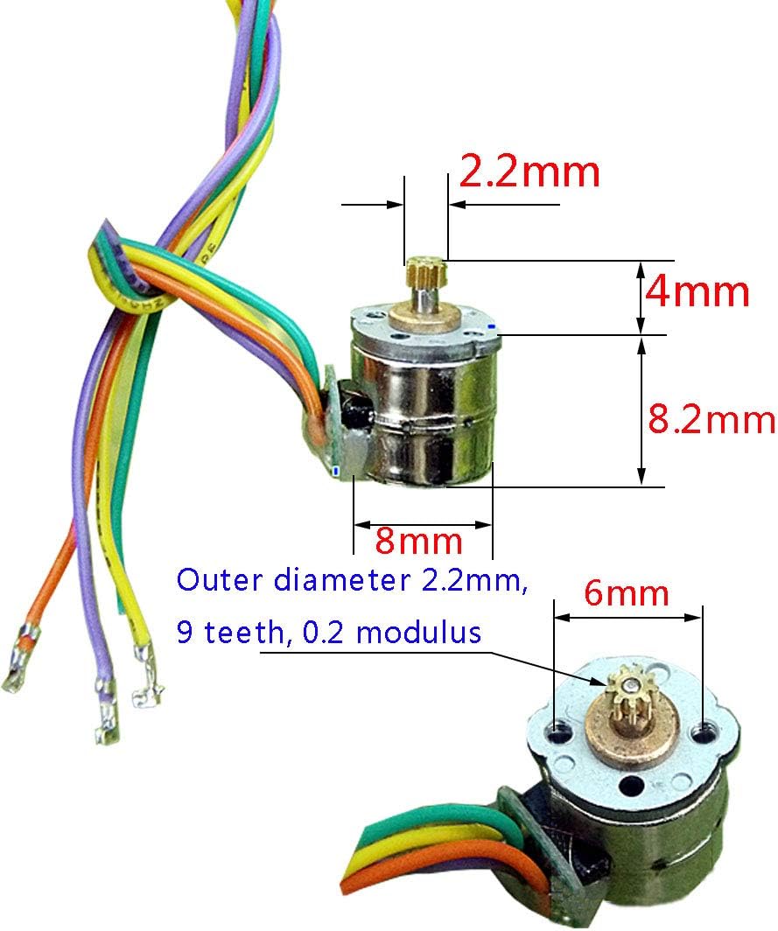
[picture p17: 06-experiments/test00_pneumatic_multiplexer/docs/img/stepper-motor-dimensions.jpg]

(output shaft diameter: 1.5mm)

## stepper motor driver
TMC2208 from [Aliexpress](https://nl.aliexpress.com/item/1005004014058136.html) at €2.04 per piece.

| specifications | |
|-----|---|
| model | MC2208 V1.2 |
| motor voltage range (VM) | 4.75V-36V |
| motor continuous current | 1.4A |
| motor peak current | 2A |
| logic voltage range (VIO) | 3-5V |
| microsteps | 256 |

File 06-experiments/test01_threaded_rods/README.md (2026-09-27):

# Legacy test — threaded rods

This is a **legacy test** preserved as historical design evidence. It predates
the current suggested testing framework and does not need to be migrated to it.

The directory contains OpenSCAD iterations of threaded rods/bolts and matching
cube geometry. Its original source structure is intentionally kept intact.

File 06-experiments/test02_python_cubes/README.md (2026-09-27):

# Legacy test — Python cubes

This is a **legacy test** preserved as historical design evidence. It predates
the current suggested testing framework and does not need to be migrated to it.

The experiment captures an earlier Python/SolidPython approach to the moving
cube/display-element geometry. Its original code and layout are intentionally
kept intact.

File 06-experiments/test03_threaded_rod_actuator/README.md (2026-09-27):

# Legacy test — threaded-rod actuator

This is a **legacy test** preserved as historical design evidence. It predates
the current suggested testing framework and does not need to be migrated to it.

The directory contains an OpenSCAD actuator/frame iteration based on threaded
rods together with its calibration and mechanical parts. Its original source
structure is intentionally kept intact.

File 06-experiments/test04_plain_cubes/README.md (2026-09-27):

# Legacy test — plain cubes

This is a **legacy test** preserved as historical design evidence. It predates
the current suggested testing framework and does not need to be migrated to it.

The experiment explores a simpler cube/frame direction and retains its original
design documents and source files. Its historical structure is intentionally
kept intact.

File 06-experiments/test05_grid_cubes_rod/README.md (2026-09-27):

# Legacy test — grid, cubes, and rod

This is a **legacy test** preserved as historical design evidence. It predates
the current suggested testing framework and does not need to be migrated to it.

The experiment is an OpenSCAD iteration combining the grid, moving cube/display
elements, and actuator rod. Its original source structure is intentionally kept
intact.

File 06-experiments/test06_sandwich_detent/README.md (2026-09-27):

> **Legacy test.** This directory is a preserved historical experiment. It does not need to conform to the current suggested testing framework, file layout, API, programming language, or simulation stack. Keep its original approach intact unless the experiment is intentionally being revisited.

# Trial 6 — sliding release grid (1×5 test strip)

Implements the three-layer sandwich: a guide grid for the pins, a sliding
3D-printed "wire comb" that locks/releases them, and a cover grid on top.
Pins carry a sawtooth rack recessed in a groove on one face; blade tongues
on the sliding strip reach into the groove. Push a pin up and the ramps cam
the strip aside against a rubber band (click); load a pin down and the flat
tooth face presses on the blade top (locked); pull the strip 1 mm and every
pin drops to the floor plate.

Everything is in `test-strip.scad` (vanilla OpenSCAD, no libraries).
Pick the part with the `part` variable or `-D 'part="..."'`, or use the
pre-exported STLs in `stl/`. `section.scad` renders a cut-open assembly
for inspection.

## Key dimensions (defaults)

| parameter | value | meaning |
|---|---|---|
| pitch | 8.5 | 3 pins per 1-inch D&D square |
| pin_w | 6.0 | square pin width |
| travel / levels  | 30/6  | 5 mm per elevation level |
| release_travel | 1.0 | strip slide to release |
| engagement | 0.7 | blade overlap over the tooth tips |
| pin_clear | 0.3 | pin–channel clearance per side (loose!) |

The loose channel fit is intentional: holding comes from the detent, not
friction, so print variance in the channels does not matter.

## Printing

| part | qty | orientation | notes |
|---|-----|---|---|
| pins_print | 1 | as exported (lying down) | groove faces up — clean teeth  |
| grid_bottom | 1 | as exported | 3+ perimeters |
| release_strip  | 1 | flat | PETG preferred (cam wear) |
| grid_top | 1 | as exported | |
| floor_plate | 1 | flat | |
| push_rod | 1 | vertical, or use 3.5 mm rod stock | |

PETG recommended throughout; PLA works for the grids. 0.2 mm layers.

## Assembly

1. Bolt `floor_plate` under `grid_bottom` (4× M3).
2. Drop `release_strip` into the pocket, stem out through the east slot.
3. Bolt `grid_top` on (same M3 bolts).
4. Loop a rubber band from the stem paddle hole around the peg on the east
   wall. The band pulls the strip west = engaged. Band tension sets the
   click force — start light.
5. Pull the stem (released) and drop the pins in from the top, groove
   facing east toward the blades — they only seat in that orientation,
   which is the point of the groove key. Let go of the stem.

## Test protocol

1. Click: push a pin up from below through a floor hole with the rod. It
   should click in clean 5 mm steps. Too stiff → lighter band or reduce
   `engagement`. Doesn't hold → tighter band or increase `engagement`.
2. Lock: press a raised pin down hard. It must not move. Stand weights on
   it (a mini is ~0.3–0.5 N; test to 5 N+).
3. Level accuracy: raise to each of the 6 levels, measure heights.
4. Release: pull the stem — all raised pins must drop freely to the floor
   plate. If any hang, increase `pin_clear` or check for stringing in the
   channels.
5. Re-engage: let the stem go with all pins down; raise a pin one click to
   confirm the blades re-entered the grooves.

## Tuning knobs

- `seat_gap` (0.1): vertical slack at each detent; raise if blades rub.
- `strip_clear` (0.25): strip sliding fit; raise if the strip binds.
- `tip_recess` (0.4): how far tooth tips hide below the pin face.
- `tooth_land` (2.0): vertical land = tolerance to height error.

## Scaling notes (beyond this test strip)

- Multi-row boards: slice the release layer into one strip per row sharing
  a common release bar, so pushing pins in one row cannot momentarily
  unlock other rows. The strip module already is exactly one such row.
- The inter-pin budget rules: `pitch − pin_w ≥ bridge_t + release_travel
  + 2×strip_clear`. Grow pitch or shrink pins before growing travel.
- Surface coverage upgrade ("stepped pins"): make the visible pin body
  nearly full pitch width and move the groove + rack to a narrower tail
  running in a lower tier. Same sandwich, hidden mechanism, ~90% coverage.

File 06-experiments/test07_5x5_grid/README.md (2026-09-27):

> **Legacy test.** This directory is a preserved historical experiment. It does not need to conform to the current suggested testing framework, file layout, API, programming language, or simulation stack. Keep its original approach intact unless the experiment is intentionally being revisited.

# Trial 7 — sliding-release grid (5×5), capped pins

Carries over trial 6's three-layer "sandwich" detent — it works well, so most
of the geometry is reused unchanged. Two display-side changes plus the start of
the under-display **caddy** are the point of this trial:

1. **Capped pins.** The rack groove now stops below the top, leaving a clean
   solid square cap (~14 mm) as the visible display surface — no groove notch on
   top any more.
2. **A real grid.** Parametric `n_cols × n_rows`, default **5×5**, instead of the
   1×5 test strip. One independent release comb **per row** (so camming a pin in
   one row can't momentarily unlock its neighbours), tiled at the row pitch.
3. **An under-display caddy.** A low cart that rides *under* the display on a
   Y-rail, raises a whole row of pins with flexible push-rods, and trips the
   spring-held lock from below — see **Caddy / actuation** below.

The display stack is in `grid.scad`; the caddy is in `caddy.scad` (which pulls
`grid.scad` in as a library for shared dimensions). Both are vanilla OpenSCAD,
no external libraries. Pick a part with the `part`/`show` variable or `-D`, or
use the pre-exported STLs in `stl/`. `section.scad` renders a cut-open display
row for inspection.

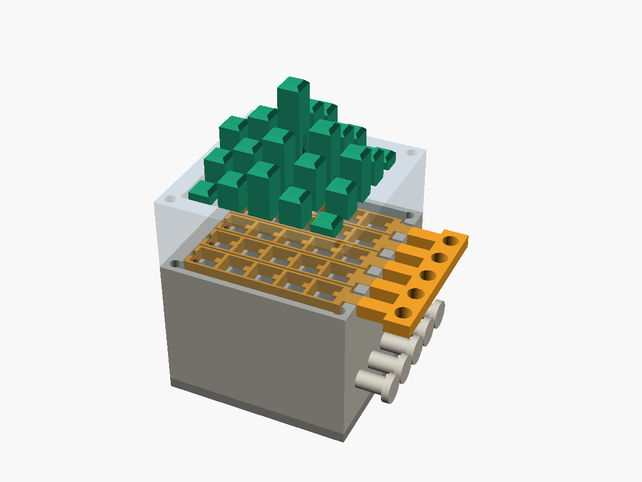
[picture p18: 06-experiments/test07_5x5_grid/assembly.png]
assembly

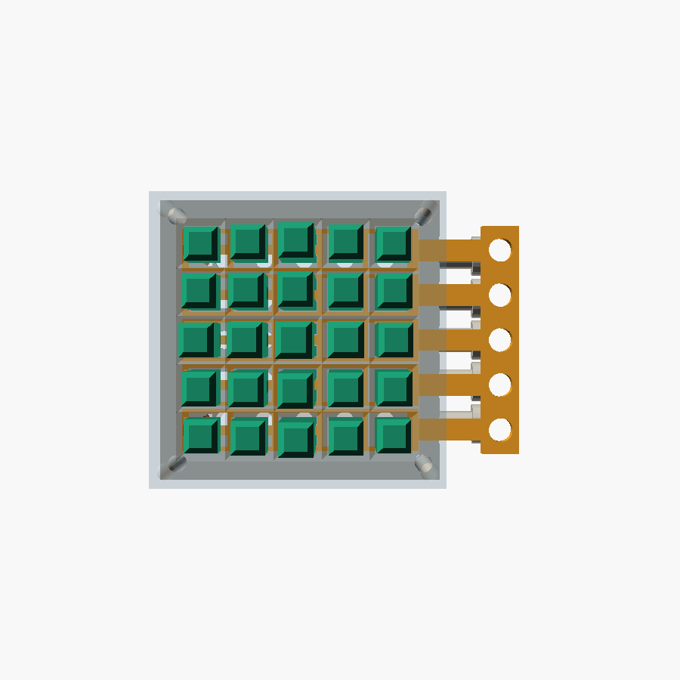
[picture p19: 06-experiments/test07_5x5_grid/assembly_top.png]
top view


## How the detent works (unchanged from trial 6)

Pins carry a recessed sawtooth rack inside a groove on one face. Blade tongues
on each row's release comb reach into the groove:

- **push a pin up** → the ramps cam the comb sideways against its return band,
  then it snaps back → *click*, one level (5 mm) gained, held.
- **load pushed down** → the flat tooth face presses on the blade top → *locked*.
- **slide the comb 1 mm** → the blades clear every tooth in that row → all pins
  in the row drop to the floor plate.

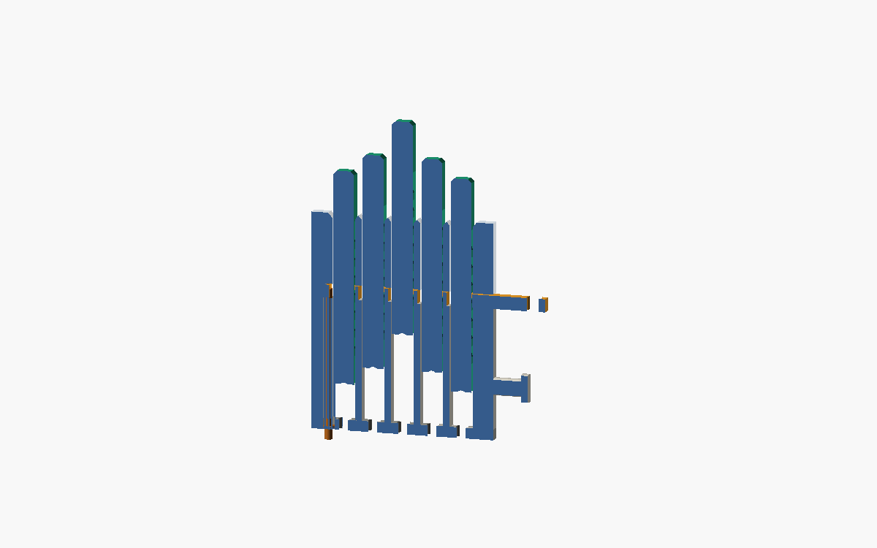
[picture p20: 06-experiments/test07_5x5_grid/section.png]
row section


## Key dimensions (defaults)

| parameter | value | meaning |
|---|---|---|
| n_cols × n_rows  | 5×5 | grid size (parametric) |
| pitch | 8.5 | pin pitch (3 per 1-inch D&D square) |
| pin_w | 6.0 | square pin width |
| travel / levels  | 30/6  | 5 mm per elevation level |
| cap_h (derived)  | 14.2  | solid pin cap kept above the rack |
| release_travel | 1.0 | comb slide to release a row |
| engagement | 0.7 | blade overlap over the tooth tips |
| rail_t (derived) | 0.65  | row-rail thickness (auto from pitch) |

### Note on multi-row packing
At `pitch = 8.5` the five row combs tile the top almost edge-to-edge, so the row
rails come out thin (`rail_t ≈ 0.65 mm`, vs 1.5 mm on the trial-6 strip). The
*column bridges* between pins (1.0 mm, loaded in the cam direction) carry the
real load, so this is workable in PETG, but if the combs feel floppy, bump
`pitch` to ~10 mm and `rail_t` climbs back to trial-6 territory (at the cost of
D&D density). Everything is parametric.

## Printing

Display stack (`grid.scad`):

| part | qty | orientation | notes |
|---|-----|---|---|
| pin | 25  | lying down, groove up | `pins_print` lays out a batch  |
| grid_bottom | 1 | as exported | 3+ perimeters |
| release_strip  | 5 | flat | PETG preferred (cam wear) |
| grid_top | 1 | as exported | |
| floor_plate | 1 | flat | |
| release_dowel  | 5 | vertical, or use 2 mm rod| hangs from each comb (release) |
| push_rod | 1 | vertical, or 3.5 mm rod  | hand-test tool |

Caddy (`caddy.scad`, printable parts):

| part | qty | notes |
|---|-----|---|
| caddy_tube_block  | 1 | 5 guide tubes, rank → row fan-in |
| caddy_feeder_print| 5 | feeder block (hobbed wheel + sprung idler added) |
| caddy_base_print  | 1 | base plate + linear-bearing bushings |

Plus hardware: 5 feed micro-servos + 1 release micro-servo (SG90/FS90R class),
2 Y guide rods + bushings, ~1.75–3 mm filament for the push-rods, rubber bands.

PETG recommended throughout; PLA works for the grids. 0.2 mm layers.

## Assembly

1. Bolt `floor_plate` under `grid_bottom` (4× M3).
2. Drop the five `release_strip` combs into the tray, stems out through the east
   slots, one per row.
3. Bolt `grid_top` on (same M3 bolts).
4. Loop a rubber band from each stem paddle around that row's east-wall peg. The
   band pulls the comb west = engaged.
5. Pull a stem (released) and drop that row's pins in from the top, groove facing
   east toward the blades. Let go of the stem.

## Caddy / actuation

A low cart rides under the floor plate on a Y-rail and sets one **row** at a
time, stepping through the five rows. Per-column **flexible push-rods** (1.75–3 mm
filament) are the heart of it.

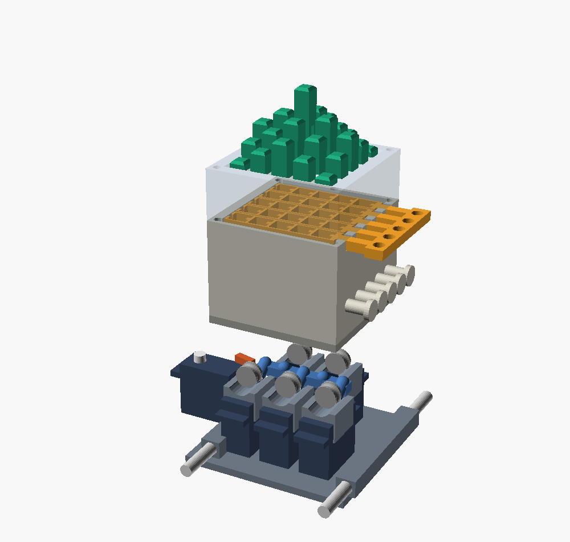
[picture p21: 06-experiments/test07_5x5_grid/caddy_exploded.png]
exploded

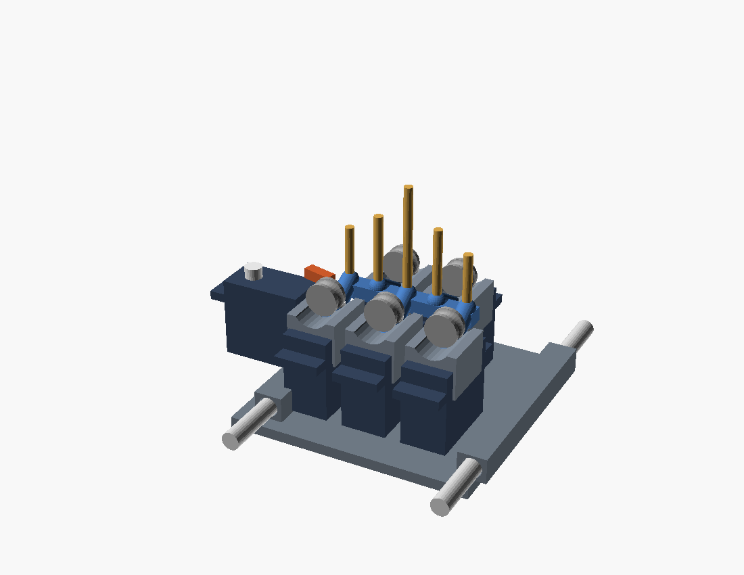
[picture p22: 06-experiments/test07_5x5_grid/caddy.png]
caddy


### Why flexible rods (the kinematics)
To raise a pin to level *k* the rod tip must reach the pin's bottom, which
*climbs* 5 mm per level — up to ~30 mm at the top. So whatever pushes has to be
able to reach 30 mm above the floor. A rigid rod/rack/lead-screw that retracts
between rows must therefore live in ~30 mm of vertical room (hanging below the
caddy or sticking up) — *not* low. A **flexible rod stored horizontal and fed
vertical** needs almost no vertical storage: only the *fed* length is upright.
That is exactly Sander's instinct, and it's the right call for a low caddy.

The pin's own detent holds every click, so the feeder only nudges the rod a
little at a time ("pump") and the rod follows the pin up. Between rows the tips
retract below the floor and the caddy steps in Y.

### Fanning out the servos
Five servos can't sit at the 8.5 mm pitch. They **stand in two ranks**
(front/back); each is only 12.6 mm wide, so alternate columns clear, and the
guide tubes fan in Y from the ranks to the row centre line. Cost: the caddy
footprint is ~3× the grid in Y (the servos sprawl front and back). Caddy height
is ~one standing servo (~30 mm) — the low dimension we cared about.

### Releasing the lock from below
Each row comb carries a **release dowel** (`release_dowel`, or a 2 mm rod) that
drops through slots in the guide and floor plate to the caddy plane. A
micro-servo **release finger** on the caddy nudges the parked row's dowel ~1 mm
east to disengage that row; the band snaps it back. Sweeping all five rows
clears the board.

### How a frame is drawn
1. Sweep the rows, tripping each release dowel → every pin drops to the floor.
2. For each row: park under it, feed each column's rod up to its target level
   (the detent clicks and holds), then retract the tips and step to the next row.
3. To change the picture, go back to step 1.

### Status & the main risk
This is the **first printable iteration**: chassis, tube block, 2-rank servo
layout, rod routing and release finger are modelled; the feeder internals
(hobbed wheel + sprung idler, like a printer extruder) are schematic and expect
physical tuning. The **key risk is rod buckling**: above the floor the fed rod
is only loosely guided by the pin channel, so at the highest levels a thin rod
may bow. Mitigations to test: a stiffer rod (PETG/nylon, 2.5–3 mm), letting the
6.6 mm channel act as a buckling restraint, or capping practical travel at ~4–5
levels. If buckling proves limiting, the rigid-chain ("zip-lift") variant is the
fallback — it stores flat too but can't buckle.

Views: `show = assembly | section | exploded | caddy | tube_block | feeder |
release | base` (e.g. `openscad -D 'show="exploded"' caddy.scad`).

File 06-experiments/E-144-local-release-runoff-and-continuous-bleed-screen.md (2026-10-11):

---
status: complete
builds-on: [E-143, E-109, E-079, E-090, E-139]
---

# Local bleed escapes a blocked exhaust, not sustained opening energy

**Stop the finite run-off pickup and this continuously bleeding air release before
finite contact construction.** Run-off stays OPEN if its pickup stalls on the
opening face. Permanent chamber bleeds permit return after finite supply loss even
with a blocked common exhaust, but cannot defeat sustained opening pressure. Their
response/air-power tradeoff and unresolved terminal route prevent promotion. This
is a scoped embodiment decision, not a fluid/escapement ban. No machine selected.

Input main `5793835`; reproduce with Python 3 standard library:
`python3 tools/curated-experiment-checks/E-144/local_release.py`.
Evidence: reduced state constraints, fluid/spring equilibrium, numerical pressure
integration and deterministic uncertainty boxes; self-review. No finite assembly,
contact dynamics, calibrated process prior, hardware or failure-rate claim.

## Causal comparison and prior failures

Recombinations, not claimed novelty: E-079 trips a command pin for passive seating,
not sustained brake clearance/loss detection; E-090 rejects rigid shared-depth
insertion; E-139's dwell cannot dissipate free-input energy. E-109's small valve
spring fails its pressure/coil-bind box. Neither that spring nor hydraulic-only
service-load retention is reused here.

All options keep separate reversible drives, grounded spring jaws **beyond capture**,
6,400 parked supports/returns and actual output proof. Spatial docking selects rods;
transverse opening allows independent rod movement/reversal, but **not independent
jaw closing**. Motors or proved parked handback hold early finishers until bank
closure. Unchanged columns remain on parked supports isolated from release.

| Option | OPEN dwell / CLOSE cause | Failure |
|---|---|---|
| Rigid tie, E-143 control | Hold bar / return bar | Local or common jam propagates |
| Run-off pickup | Finite flat maintains gap / pass its edge | Stall on flat holds OPEN |
| Run-off plus latch | Latch stores OPEN / unspecified trip | Local loss/reset path still absent |
| Sole-exhaust pressure control | Supply pressure / common vent | Blocked exhaust traps pressure |
| Permanent chamber bleed | Continuously replenish air / remove supply energy | Local vents survive common exhaust obstruction; sustained supply holds OPEN |

## Run-off dwell and reset witness

Grant a 2-mm rise, 10-mm flat and ideal immediate closure beyond the edge. A
20-mm/s sweep gives **.5-s full opening**: useful for nominal .4-s/40-mm rod travel
plus .05-s local operations. Yet a pickup seized at 7 mm holds full gap indefinitely;
passing 12 mm requires the very common motion whose failure must be tolerated.
This is a reduced unilateral support constraint, not generated contact geometry.

Longer dwell increases vulnerable positions. Rod-driven run-off fails on a
stationary/reversing rod. A timer with repeated refresh changes the mechanism; an
OPEN latch requires an explicit loss-safe CLOSE cause. Reset over the same face
reopens the jaw: bypass/one-way return or proved parked support must precede rearm.
No finite section earns promotion from the granted run-off behavior.

## Concrete pneumatic circuit and force/volume model

Tankless source → common feed → parallel spring-return chambers, each with its own
permanent atmosphere outlet **downstream of any branch obstruction**. No check
valve traps pressure away from its bleed; no shared muffler is granted clog immunity.
An optional common dump is excluded from loss-return calculations. Springs/pads
ground rod loads; pressure only opens them. **One drive losing power while the
common pump stays on does not close that head**; a local valve/disconnect is extra.

Explicit scenario, not a sourced manufactured device: air at 293.15 K, atmosphere
101,325 Pa, source .5 MPa gauge. Summed effective piston area A=**2,400 mm²/head**,
stroke g=.4 mm, preload 800 N ±20%, slope k=200,000 N/m and adverse return-guide
shunt S=40 N. An equivalent coordinate represents both jaws. Its area diameter is
55.3 mm: internal machinery, not relaxed 5.08-mm tops. Source force 1,200 N exceeds
960+80+40=1,080 N adverse opening force. Work is ≥**.416 J/head** at that corner
before other losses; swept volume **.96 ml/head**. Ideal leverage preserves work.

At minimum preload N=640 N, quasi-static return is
`q=clip((A*p_g+S−N)/k,0,g)`. Motion starts at 283.33 kPa gauge; contact occurs at
250 kPa. After contact, `D=.02*(N−S−A*p_g)`: contact is not useful holding force.
**11-N capacity** occurs at **20.833 kPa gauge**, one newton above E-143's assumed
10-N load. This is a comparison threshold, not an accepted arrest/drop requirement.
Atmospheric capacity is 12 N; shunt S=160 N instead leaves 9.6 N and fails even
fully vented. Actual jaw seizure is outside this equilibrium return assumption.

`V=V_dead+A*q+C*p_g`. Closed dead volume includes chamber and allocated tubing/feed:
2 ml baseline, .25/14 ml alternatives. Wall compliance C gives expansion at .5 MPa
of 0/.2/1 times dead volume. “No accumulator” does not remove trapped gas, spring
sweep, line expansion, compressor-head volume or pump coast. Uncounted connected
source volume invalidates response figures.

## Flow, thermal and coherent manufacturing sensitivity

Use the ideal-gas choked/subcritical nozzle law from
[NASA GUNNS, Orifice Flows](https://github.com/nasa/gunns/wiki/Standard_Flow_Equation#orifice-flows),
with [NASA Glenn's sonic relation](https://www.grc.nasa.gov/www/k-12/airplane/mflchk.html)
as a separate choked check (accessed 2026-10-11). Cd=.7 baseline, .4/.9 bounds are
**assumptions**, not print priors. Short-orifice theory does not validate long rough
printed capillaries.

For absolute pressure p, polytropic n, `T=T0*(p/p0)^((n−1)/n)` and
`dt/dp=(V/n+p*dV/dp)/(R*T*mass_flow_out)`. Chamber mass balance with well-mixed
isothermal n=1 or adiabatic n=1.4 blowdown includes piston/wall volume change.
Integrate separately at jaw-stop, seated and sonic boundaries. Jaw inertia,
asymmetry, bounce, seal stick-slip and propagation delay are excluded: results are
**equilibrium-capacity times, not actual arrest predictions or bounds**.

Baseline: isothermal, 2-ml dead volume, rigid walls, no pump coast:

| Bleed diameter | First contact | 11-N capacity | Ambient air L/min/head during dwell | Ideal compression W/head |
|---|---:|---:|---:|---:|
| .10 mm | 2,295 ms | 4,291 ms | .389 | 1.17 |
| .25 mm | 367 ms | 687 ms | 2.43 | 7.31 |
| .50 mm | 91.8 ms | 171.7 ms | 9.72 | 29.23 |
| 1.00 mm | 23.0 ms | 42.9 ms | 38.88 | 116.94 |

Reversible isothermal compression `mass_flow*R*T*ln(p0/p_atm)` is a lower power
bound **for this air-supply embodiment**, excluding inefficiency, charging and rod
drives. The .5-mm case at 121 simultaneously open heads consumes **1,176 ambient
L/min and ≥3.54 kW** during dwell. No product power ceiling or universal cost
exclusion is inferred; the proposed low-energy release benefit fails. Staggering
banks reduces peak open heads while constraining concurrency/speed/head inventory.

Adiabatic baseline gives **146.3 vs 171.7 ms**. Across 18 dead-volume/thermal/wall
combinations at .5 mm: **62.5–1,709.9 ms**. Sixteen coherent isothermal corners
(d=.45/.55 mm, Cd=.4/.9, V_dead=1.5/2.5 ml, wall expansion=0/.2) give
**91.2–498.7 ms**, not statistical tails. Nozzle bias/roughness and line expansion
can shift a whole bank together. Blockage is a separate topology fault, not a
Gaussian outlier. No qualified X1C bounds exist here for layer/first-layer effects,
warp, shrinkage, seals, alignment, spring creep/fatigue or wear; no yield follows.

Pump coast is an explicit envelope: hold at most p0 for 0/10/50/200 ms, then zero
inflow. Adding these to the upper isothermal box gives **498.7/508.7/548.7/698.7 ms**.
No real pump is shown to satisfy that bound. Continued motor power, connected tank
or indefinite replenishment defeats it. A stuck live feed is not a blocked exhaust.

Resizing A, N, k, S together for μ=.1/.3 preserves thresholds and 11-N capacity.
If all dead volume scales too, .5-mm-bleed times fall to **34.3/11.4 ms**; with
fixed 2-ml lines they remain **129.7/122.7 ms**. An illustrative 10-ms threshold
requires ≥**100.4/33.45 W/head** compression even in the fully scaled cases
(501.8 W at μ=.02); fixed lines require 379.2/358.7 W. Ten milliseconds is not an
accepted requirement. Liquid circuits need their own compliance/swept-volume model;
air results do not reject every fluid release.

## Fault graph, rearm and interface inventory

The executable finds connected pressure components: after source loss each needs
an atmosphere outlet. It grants unrestricted connections and spring return; counts
are **eventual vent paths, not proved arrested rods**:

- Blocked sole exhaust: 0/8; permanent chamber bleeds with that fault: 8/8.
- Supply obstruction partitions the bank: 8/8 with intact local bleeds.
- One blocked bleed, connected branches: 8/8 through the other seven. Identical
  perfect-manifold response grows by 8/7; real restrictions need a network model.
- Blocked bleed plus isolated branch: 7/8 (**two faults**, not one blockage alone).
- Sustained source, or coherent blockage of all outlets: 0/8.

Rearm: prove support, charge, prove clearance, move, hand back, vent/prove, index.
Baseline charge from atmosphere requires **18.74 mg air/head** including piston
sweep. Even a constant source twice steady .5-mm-bleed flow takes **48.0–96.1 ms**
by ideal isothermal net-mass bounds, before line/settling losses. Exactly steady-flow
capacity cannot deliver instantaneous full-pressure reset. Common pressure/bar
position cannot prove a local jaw; jaw position alone cannot prove grip. Failed
proof retains capture and inhibits indexing, with bounded retry or isolation/repair;
false acceptance/recovery time remain unknown.

For H heads count H independent drives/return assemblies, 2H pad contacts and jaw
guides, H equivalent chambers, H moving sealed/flexing boundaries, H restrictions
and H branches. Two pistons double relevant seals. Add source/feed/dump, power,
control, proof and access. Parked supports, guides/returns and capture/handback still
repeat at 6,400 cells. Filters, quiet exhaust and readers are unpriced; printed
integration does not remove wear interfaces or assembly. No material/time estimate.

## Full-machine disposition and next discriminator

Keep 5.08-mm tops, 40-mm travel, 6,400 cells and strict <30 s. E-143's optimistic
`6+ceil(6400/H)*(.45+t_extra)` includes six seconds preparation/registration/proof/
retry/settling and .45 s/head wave travel/local operations. Extra .01/.05/.1/.2 s
requires **124/137/149/178 heads**, versus 121 with no extra time. Using .5-mm local
bleed each wave gives **169 heads** before recharge. A common normal dump can improve
normal timing, not the failed-dump response; overlap requires an actual supported
schedule. E-132's dense-route collision and E-142's capture elasticity remain open.

Joint purchases stay <$500, ideally <$200. With inherited hypothetical $250 shared
allowance and $1.56/motor comparison, 121 heads leave <$61.24 for all other purchases;
134 leave <$40.96; 169 already exceed budget by $13.64. E-143's motor rated-power
failure remains. No fresh quote, free spring/pump, complete BOM or durability pass.

**Decision:** preserve local bleed as a conditional common-exhaust-fault improvement,
but stop these embodiments. Reopen run-off with local return independent of a seized
pickup. Reopen fluid release with enforced finite supply energy, credible response/
flow budget and chamber-side vent/recovery paths. Sustained pressure cannot mean
both OPEN and loss-safe CLOSE to the unchanged passive chamber. No fabrication.

**Next:** compare shared electromagnetic opening fields and mechanically separate
spring armatures against bleed. This removes a common moving return bar/expelled-air
loss; it differs from E-143's priced per-head solenoid array. Cross-check E-138;
screen pole/gap force, stuck-armature flux redistribution, current turn-off including
suppression/remanence, dwell heating, lever work, repeated magnetic parts and joint
cost. Powered stuck commands still require a separate interruption path. Stop if
common moving poles, per-head active release or assumed free precision magnetics
are the only escape; a survivor earns a finite bank section, then terminal routing.
No purchase, print, staffing or CEO approval is needed.

Self-review: sonic expression/continuity, zero-flow limits, area/volume scaling and
chamber mass derivative. Fixed-volume choked exponential: .0509405281 s vs numeric
.0509405275 s. Baseline 64/128/256/512 subdivisions per smooth interval:
.171648963/.171649993/.171650251/.171650315 s. These verify the reduced calculation,
not real flow/contact fidelity. Graph checks and stalled-flat witness are separate.

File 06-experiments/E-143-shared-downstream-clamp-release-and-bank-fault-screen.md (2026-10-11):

---
status: complete
builds-on: [E-142, E-132, E-109]
---

# Shared release saves commands, not clamp work or independent arrest

**Stop the rigidly tied crossbar, single common-return fault paths and the sourced
motor/release combinations below.** Unilateral lifters and separate slack tendons
isolate a stuck follower *if the common member returns*, but do not survive that
member staying open. No embodiment earns a finite transient/contact build yet.
This does not reject all shared releases or inexpensive motors. No machine selected.

Input main `c7bbb97`; Python 3 standard library:
`python3 tools/curated-experiment-checks/E-143/shared_release.py`.
Evidence: deterministic analytical screens, exact kinematic constraints and sourced
procurement examples; self-review. No generated assembly/contact geometry, physical
measurement, qualified spring/friction/process prior or hardware-performance claim.

## Causal combinations and location of arrest

All variants retain separately powered reversible spatial heads, 6,400 parked
supports/returns, capture before unlocking, actual output readback and proved
handback. 5.08-mm tops, 40-mm travel and ~6,400 cells remain fixed. Head equipment
may occupy larger internal pitch; shared release does not supply lift work.

The proposed series path is **motor → transmission elasticity → head rod → retained
capture → column stem → top**. Grounded jaws on the head rod eliminate only the
upstream transmission compliance. E-142's capture clearance/compliance is still
*downstream* and cannot disappear. A useful terminal clamp must grip the column-side
stem beyond that capture, or independently bound its remaining elastic energy,
backlash and stem bending. The frame must also arrest lateral docking motion;
a jaw mounted on a freely moving writer is not grounded.

E-132's lateral eye/elbow still collides with a third row; E-142's isolated eye
does not repair it. Integral extended stems could change access but need generated
clearance through unequal neighbors and docking. Permanent terminal jaws instead
repeat 6,400 assemblies. No dense terminal route is constructed. Even with an instant
fixed head rod, m=1.1 kg, v=.1 m/s and residual K=100/1,000/10,000 N/m permit
**10.488/3.317/1.049 mm** oscillation about equilibrium before backlash: an independent
placement bound, not another E-142 simulation or an allowable-drop criterion.

| Arrangement | Causal mechanism and failure |
|---|---|
| Per-head coil control | Individual coils open frame-backed spring jaws; independent closure possible. 121/229 Adafruit 412 units cost $726/$1,374 before motors: reject this purchase embodiment |
| Crossbar | Two driven ends lift a bar; 20:1 levers open jaws transverse to independent rods. Local springs and a separate bar spring return it. Rigid ties propagate follower jams; unilateral lifting faces separate on return, but common bar/drive jam still holds all open |
| Tendon payout | Separately routed tension-only branches open local levers; a powered yoke tensions them, and a separate spring pays out slack. Branch jams can stay local; yoke/guide jam defeats all. No free gravity return or backdrivable gearbox |
| Pressure manifold | Pressure opens separate spring jaws; normally open exhaust dumps on loss. Springs ground the load. A blocked branch traps one release; blocked sole exhaust traps all. Extra vents/disconnects add hardware; this is not fluid-only holding |

Tendon/unilateral lift are related decoupling variants; pressure is the different
shared arrangement. E-132 permanent drag retains its moving-arrest/heating failure.
No literature novelty or landscape saturation is claimed.

## Summed force/work, leverage and manufacturing sensitivity

**Explicit screening box, not a sourced process prior:** F=10 N service load,
100 mm/s output speed; kinetic/static friction floor .02, or competing .1/.3
assumptions; two flat opposing pads, each 4×10 mm; total spring preload NΣ=800 N
±20%; gap per pad .2–.4 mm. This gives minimum ideal drag .02×640=12.8 N,
only 2.8 N above F. These are scenario loads, not new product requirements.
Direct linear drag is μNΣ: E-142's 16-mm disc / 2-mm output amplification is gone.
Pad pressure spans **8–12 MPa** before contact nonuniformity, not qualified PLA
capacity. Normal loads are transverse and add even though their vector sum cancels.

The 20:1 opening lever trades force for travel: Finput=NΣ/20 and travel=20g.
At +20% preload and .4-mm gap, **48 N/head over 8 mm**, ≥.384 J/head;
eight heads require **384 N and ≥3.072 J**. Lower corner is .128 J/head.
These ideal preload contributions exclude spring-force rise, lever/guide friction,
bar strain and acceleration. A 2-mm short lever arm implies a 40-mm long arm;
finite swept geometry/bearings remain unconstructed. Leverage preserves work.

Re-sizing to the same 12.8-N minimum ideal drag at μ=.1/.3 reduces nominal NΣ to
160/53.33 N; an eight-head adverse preload/gap case still costs **≥.6144/.2048 J**.
These alternative coefficients are uncertainty choices, not material selection.
[Adafruit 412](https://www.adafruit.com/product/412), accessed 2026-10-11, lists .5-N
starting force, 5-N retentive force, 5.5-mm throw and $6 at 100+. Even *granting*
5 N throughout its stroke gives .0275 J. Under that optimistic flat-force envelope,
the three eight-head cases need at least **112/23/8 units' work**, not one actuator.
This envelope is an assumption based on the endpoint rating, not a measured force
curve or universal solenoid bound. The actual .5-N start also contradicts direct
48-N/head opening. Levers cannot repair an energy deficit. A motor release can
supply repeated work, but a self-locking reducer needs a separate loss-safe disconnect.

Guide friction can shunt spring force into the housing before pad loading. A bounded
0/40/80/160-N total shunt at −20% preload leaves **12.8/12.0/11.2/9.6 N** drag at
μ=.02. Last corner fails static hold; even 80 N cuts arrest margin to 1.2 N. This
bound labels uncertainty in guide alignment, roughness and side load, not an invented
probability. For eight freely following ideal levers, local return forces total
256 N at the bar; a **separate assumed 10-N ±20% bar spring** adds ≥8 N. With common
bar/drive resistance 0/50/300 N, net return is **264/214/−36 N**. One head gives
40/−10/−260 N. Unknown motor detent, guide wedging or cable seizure cannot be erased
by setting motor torque to zero. A stuck-open follower supplies no return assistance;
all followers stuck leave only the dedicated spring. No return actuator is selected.

For the pressure arrangement, an assumed .5 MPa opening supply requires ≥1,920 mm²
summed piston area/head at 960 N (equivalent single diameter 49.44 mm); eight heads
with .4-mm piston motion displace ≥6.144 ml. Levers can reduce area only by increasing
travel/volume-related work. Diaphragm strain, seals, exhaust conductance, tubing,
pressure supply and local vent failure are unpriced; no closure time is assigned.

## Crossbar deflection and stuck-member discriminator

An optimistic straight, simply supported beam with both ends **driven together**
carries discrete 48-N lever loads at 40-mm internal head pitch. Rectangular section
width 10 mm, depth 10/20/40 mm; effective E=1–3 GPa is a labelled competing bound,
not an X1C PLA property. Exact point-load Green functions give the midspan maximum.
For .4-mm commanded pad gap, reserve .1 mm running clearance and .2 mm coherent
pad-equivalent gap/warp/alignment error: only .1 mm remains for beam deflection/20.

| Heads / end-drive span | Beam depth | Gap lost at E=1 GPa | Remaining pad margin |
|---|---:|---:|---:|
| 2 / 80 mm | 10 mm | .04224 mm | +.05776 mm |
| 4 / 160 mm | 20 mm | .07872 mm | +.02128 mm |
| 8 / 320 mm | 40 mm | .15456 mm | **−.05456 mm** |

At E=3 GPa the last loss is .05152 mm: positive .04848-mm margin. At .4-mm
coherent error all fail even with infinite beam stiffness; at .1 mm the 320-mm
case fits. Model choice changes the result. Deflections >span/20 are flagged outside
small-deflection validity, not precise failures. Shear, joints, bearings, return-
spring and actuator compliance are omitted favorably. Intermediate *driven* supports
reduce span but need force distribution; stationary supports cannot react along
the allowed opening motion for free. A 320-mm part needs diagonal-build analysis
or a joint on the 256-mm printer, not an assumed free seam.

The executable solves reduced kinematic constraints, **not finite contact geometry**:
with jaw opening qi≥0 and bar opening u≥0, rigid ties impose qi=u; unilateral lifters
impose qi≥u and springs minimize qi. At loss, grant u=0 unless the common mechanism
is jammed. One qi fixed open leaves **0/8** closed with rigid ties, **7/8** with
unilateral followers. A common u fixed open leaves **0/8** in both. A lagging follower
has the same isolation advantage while its opening remains positive; none of these
counts proves that its own loaded rod is arrested. Tendon slack realizes the same
constraint only with separately routed branches and no trapped tension. Pressure
release has an analogous common-exhaust fault, not a proven equivalent transient.
A bar-return sensor can therefore falsely accept a stuck local release. Local rod
stopping and jaw-force/support proof must be separate from common release readback.
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

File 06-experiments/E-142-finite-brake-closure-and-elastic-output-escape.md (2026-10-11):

---
status: complete
builds-on: [E-141, E-132]
---

# Finite closure does not make rotor arrest an output lock

**Stop individual purchased releases and adverse sliding-cam return; spring closure
remains a subsystem hypothesis.** Finite plate closure rebounds; the elastic output
can escape after rotor arrest. No machine is selected or outage drop accepted.

Input main `f5a9c31`. Reproduce with Python 3/NumPy:
`python3 tools/curated-experiment-checks/E-142/closure.py` (disposable JSON).
Evidence: sourced screening, finite sections, lumped electrical/contact simulations
and analytical energy bounds. **No assembly CAD, process calibration, physical
measurements or independent review.** Dense routing remains a separate gate.

## Release choices and necessary conditions

Inherit E-141's independent spatial heads, capture-before-support-release, signed
motion and proved support handback. The retained joint carries both force signs;
the brake grounds the shaft on loss. Neither release supplies the 6,400 parked
support/return mechanisms, selection, readback or dense route under 5.08-mm tops.

| Release | Energy and reactions | Disposition |
|---|---|---|
| Axial spring plate | Powered coil pulls plate off one shaft disc against a preloaded spring; loss dissipates magnetic energy and releases spring into pad contact. Plate keys and shaft thrust bearings return torque/normal load to frame | Finite conditional model below; custom coil, frame and controls unpriced/unqualified |
| Sliding cylindrical cam | Motor holds a ramp under the same plate; stored plate energy plus a separate torsion spring must backdrive the ramp and free motor after loss | Fails return at adverse contact friction; direct drive does not remove detent or reflected inertia |
| E-132 permanent pads | Always-grounded opposing spring pads and counterbalance; motor must drive through drag | No release latency, but adverse moving drag still produces 4.8 m/s² along travel; not repaired |
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

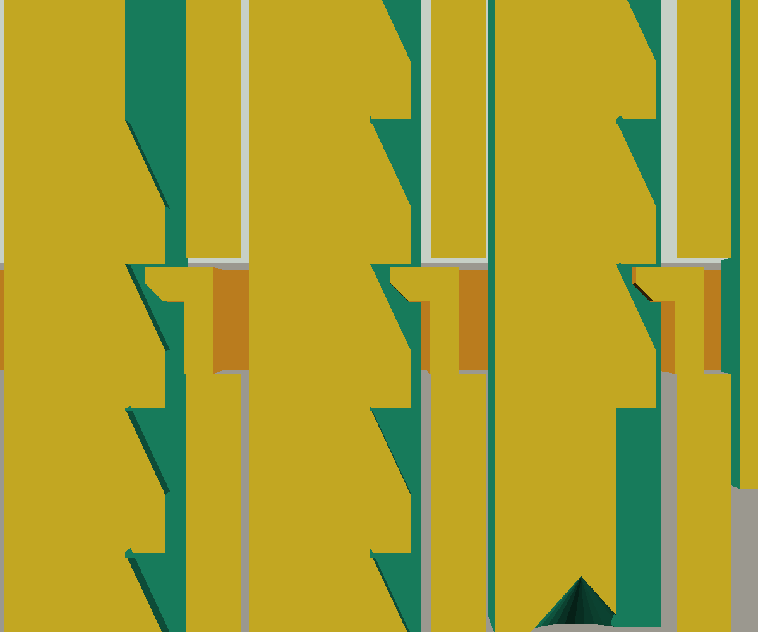
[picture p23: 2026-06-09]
06-experiments/test06_sandwich_detent/detent_closeup.png

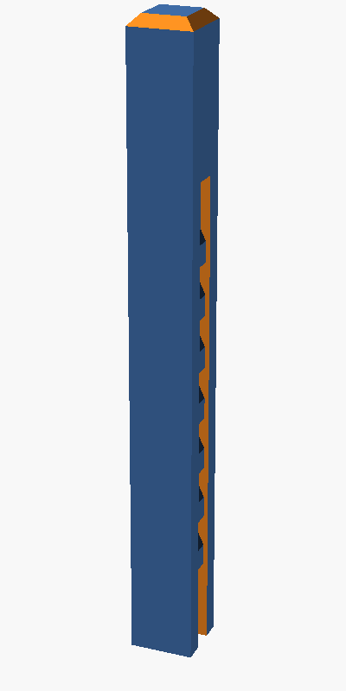
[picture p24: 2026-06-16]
06-experiments/test07_5x5_grid/pin.png

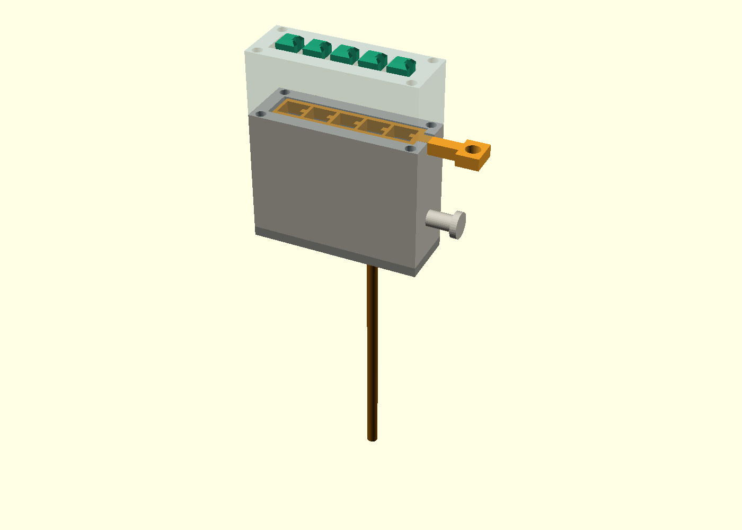
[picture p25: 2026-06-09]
06-experiments/test06_sandwich_detent/released.png

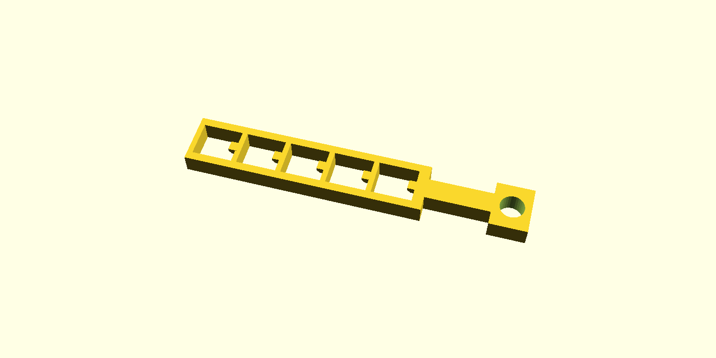
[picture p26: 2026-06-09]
06-experiments/test06_sandwich_detent/strip.png

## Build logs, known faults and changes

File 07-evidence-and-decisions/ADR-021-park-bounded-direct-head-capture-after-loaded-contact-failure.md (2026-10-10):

---
status: active
builds-on: [E-123, E-124, E-125, ADR-020]
---

# Park the bounded direct-head capture route before machine evaluation

**Decision:** close the studied direct-head mechanical gate with a scoped
rejection. Retire its dependent complete-system timing/cost evaluation. No
complete powered head survives; no fabrication, purchase or requirement change
is justified. This is an allocation decision, not proof that direct heads or
wider internal machinery cannot work.

**Basis:** E-123's centred pad cannot force lowering in its declared drag
scenario; its C shoe's nominal acquisition does not survive the finite guided
pose in E-124. E-124's bilateral cup changes the force path but leaves retention
and power absent. E-125 supplies closed channels and capped pins: adjacent
retained heads collide at the tested compact pitch. Legal 10.16-mm spacing
escapes that collision, yet taking up the actual closing walls causes the rigid
jaw to miss the upper shoulder and enter the foot side under the declared
.025-mm inward face error. These are different failures of three implemented
capture routes, not three failed complete machines.

The E-125 loaded-path rejection does not depend on the reduced contact model's
invalid fixed nodes. Direct reconstruction from the generated right-pad bounds
at q=.793470869 gives x_min=.971 mm and z_min=1.194223305 mm against a foot
ending at x=.975, z=1.2 mm. Their 1.6-mm shared depth gives
(.975−.971)×(1.2−1.194223305)×1.6 = .000036971 mm³ intersection,
matching the polygon calculation. This is an analytical self-check of rigid
geometry, not independent external validation or a physical jam measurement.

**Consequences:** retain the executable acquisition, retention, contact and
support-loss witnesses in E-123–125; stop tolerance-only refinement of this cup.
Do not inherit earlier conditional bank timing or motor budgets. The indexed
ground bolt cannot arrest every intermediate height, and positive jaw capture
does not arrest a backdrivable axis. Power, powered lock set/reset, retained
selection, finite readback, proof and safe recovery remain unimplemented; their
absence is not evidence that every possible implementation fails. They need no
further implementation on the rejected capture route. Preserve the simple
direct-head comparator without granting machine feasibility.

**Reopening:** require changed contact/channel topology or a complete sparse
head arrangement that handles loaded acquisition across the declared bounds,
arbitrary neighbour heights and full travel. A viable continuation must then
supply positive carrier arrest while ground support is withdrawn, powered ground
transfer, retained selection through proof/withdrawal, finite readback and
isolated fault recovery. More head spacing alone or a narrower unsupported
error box does not meet this condition. Separate closure/take-up, relocated
joints and moving-edge compliant capture remain untested alternatives, not
admitted survivors. Portfolio selection should compare their complete repeated
and shared machinery burden against changed force-transmission principles before
funding another detailed section sweep.

**Residual limits:** deterministic bounds are not measured X1C priors or yield
estimates. No full-board performance, cost, material strength, wear/lifetime,
readback reliability or hardware qualification has been established. Retiring
machine evaluation records a failed prerequisite; it does not establish failure
of the product requirements or end the research program.

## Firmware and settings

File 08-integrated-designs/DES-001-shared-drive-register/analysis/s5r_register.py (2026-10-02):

"""s5r register; CAD/calculation source, no physical validation."""
from __future__ import annotations

import json
import math
from pathlib import Path

UPLIFT = 1.16
BANK_DRIVER_USD = 0.7955
COST_CEILING_USD = 500.0
FIXED_PARTS_NO_CHANNEL = 218.70  # purchased base allowance; no bank channels
import timing_basis as tc

HERE = Path(__file__).resolve().parent

# ---------------------------------------------------------------------------
# Cell / register geometry at 5.08 mm pitch (mirrored in s5r_register.scad).
# ---------------------------------------------------------------------------
PITCH_MM = 5.08
ROTOR_RADIUS_MM = 1.5          # the rotor geometry (radius_mm)
ROTOR_CORE_RADIUS_MM = 1.0     # parameters.scad (core_radius_mm)
LEVELS = 5
LEVEL_ANGLE_DEG = 360.0 / LEVELS  # 72 deg per level
ROWS = tc.ROWS                 # 80
COLS = 80

# Pawl leaf: a vertical (Z) cantilever, so its length is NOT bounded by the
# 5.08 mm pitch band; only its thickness and width are in-band. The pawl is the
# LOAD-BEARING leaf, so it is 2 lines (0.90 mm) and long (8 mm) to keep the
# force low. A 0.45 mm leaf would be only 1 extrusion line (a print-risk).
PAWL_LENGTH_MM = 8.00          # Z extent of the cantilever
PAWL_T_MM = 0.90               # thickness in X (pitch direction); 2 lines
PAWL_W_MM = 0.70               # width in Y (row direction)
PAWL_DEFLECTION_MM = 0.10      # working deflection off the rack tooth
PAWL_TARGET_FORCE_N = 0.14     # design target; checked against the leaf calc

# Keeper latch: bistable over-centre leaf, 5-position gate.
# design calculation re-profile (residual-KEEPER): the design calculation keeper was 0.45 mm = 1
# extrusion line (RISK), and its hold was a bending-spring force set by the
# over-centre offset (tolerance-fragile). The keeper is now 0.90 mm = 2 lines
# (PASS) and its HOLD is a hard printed shoulder in compression; the leaf only
# trips the snap. A longer leaf (4.00 mm) keeps the snap strain low.
KEEPER_LEAF_T_MM = 0.90
KEEPER_LEAF_L_MM = 4.00
KEEPER_LEAF_W_MM = 0.70
KEEPER_OVER_CENTRE_MM = 0.06   # offset making the detent bistable
KEEPER_GATE_STEP_MM = 0.35     # spacing of the 5 gate positions
KEEPER_LEAF_T_PREVIOUS_MM = 0.45  # superseded (1 line); kept for the record
KEEPER_LEAF_L_PREVIOUS_MM = 3.00

# Drive rack on the shared bar.
# design calculation (design calculation bank close-out): the design calculation rack (pitch 0.60 / tooth 0.45)
# left a 0.15 mm inter-tooth gap that fuses at a 0.4 mm nozzle (< 0.44 mm one
# line). Re-dimensioned to pitch 1.00 / tooth 0.50 (gap 0.50 mm); the
# per-stroke advance (RACK_STROKE_MM) therefore becomes 1.00 mm, not 0.60 mm.
RACK_TOOTH_PITCH_MM = 1.00
RACK_TOOTH_HEIGHT_MM = 0.50
RACK_TOOTH_PITCH_PREVIOUS_MM = 0.60   # superseded (fused); kept for the record
RACK_TOOTH_HEIGHT_PREVIOUS_MM = 0.45
RACK_STROKE_MM = RACK_TOOTH_PITCH_MM   # one forward stroke advances one tooth
                                       # (was RACK_TOOTH_HEIGHT_MM = 0.45; the
                                       #  design calculation correction is pitch-driven)

# Shared drive bar section. design calculation/design calculation replaced the printed 3x2 placeholder
# (which failed bar torsion by ~28x) with a SOURCED steel rod d=6 mm.
BAR_D_MM = 6.0                 # sourced steel drive rod diameter
BAR_D_OPTION_MM = 8.0          # printed round PLA fallback (or sourced rod d=5)
BAR_MATERIAL = "sourced steel rod"   # or "printed PLA round d=8"

# FDM process (sourced limits, tools/fdm-limits/fdm_process_limits.py).
MIN_FEATURE_MM = 0.44          # 1 extrusion line @ 0.4 mm nozzle
MIN_WALL_MM = 0.88             # 2 lines, robust
DIM_ACCURACY_MM = 0.10         # per printed face (assumption, [R4])

# Sourced material / friction constants (DETENT_CONTACT.md / historical sourced estimates).
MU_PLA_MID = 0.35
MU_PLA_LOW = 0.20
MU_PLA_HIGH = 0.50
PLA_E_MPA = 1500.0             # sourced modulus range 700-2500, midpoint

# Service load already bounded by [design calculation]/design calculation (robust register). The latch
# never carries terrain load (the rotor hard stop does), so this is inherited.
K1_SERVICE_BOUNDING_N = 3.27
K1_SERVICE_DISTRIBUTED_N = 0.39

# Unloaded-write resistance per pawl beyond its own spring (rotor detent torque
# reflected to the rack at the unloaded write point). Stated assumption. During
# a write the platen is unloaded, so this is the light rotor detent only.
WRITE_LOAD_N = 0.05

# Bank drive: a fully-orderable NEMA17-class stepper (design calculation). The chosen
# design drives the bar from BOTH ends (BANK_MOTORS=2): that doubles the
# available force and removes bar torsion across a 4-row bank.
BANK_MOTOR_TORQUE_NM = 0.30    # sourced class figure (same as lift motor R7)
BANK_MOTORS = 2
BANK_PINION_RADIUS_MM = 6.0
BUS_EFFICIENCY = 0.6           # stated assumption for the bar/crank bus

# Writer solenoid: small 5 V push solenoid (design calculation writer class).
WRITER_FORCE_N = 1.2
WRITER_SETTLE_S = 0.05         # one comb actuation + settle (assumption)

# Chosen design point (the design calculation correction to design calculation's R=1, W=8).
ROWS_IN_BANK = 4               # bank spans 4 rows -> 20 groups, no pitch penalty
WRITERS = 40                   # 2 stations/groups of 40: writer index < bank pass

# Bank crank speed (assumed; the dominant time assumption, like S5's K6 dwell).
BANK_CRANK_DEG_S = 720.0       # 2 rev/s

# Endurance: same defensible FDM span as design calculation/K11.
ENDURANCE_EPS_SPAN = (0.0020, 0.0030)
ENDURANCE_BASQUIN_M = 8
ENDURANCE_LEAF_STRAIN = (0.05 + 0.20) * 1.5 * 0.45 / (10.0 ** 2)


def _cantilever_rate_n_per_mm(t: float, w: float, l: float,
                              e_mpa: float = PLA_E_MPA) -> float:
    """Printed rectangular cantilever rate k = 3 E I / L^3 (N per mm)."""
    i = w * t ** 3 / 12.0
    return 3.0 * e_mpa * i / l ** 3


def pawl_spring() -> dict:
    k = _cantilever_rate_n_per_mm(PAWL_T_MM, PAWL_W_MM, PAWL_LENGTH_MM)
    f = k * PAWL_DEFLECTION_MM
    return dict(rate_n_per_mm=round(k, 4),
                working_deflection_mm=PAWL_DEFLECTION_MM,
                force_n=round(f, 4), target_n=PAWL_TARGET_FORCE_N,
                within_target=bool(f <= PAWL_TARGET_FORCE_N * 1.5))


def keeper_hold() -> dict:
    k = _cantilever_rate_n_per_mm(KEEPER_LEAF_T_MM, KEEPER_LEAF_W_MM,
                                  KEEPER_LEAF_L_MM)
    hold = k * KEEPER_OVER_CENTRE_MM
    return dict(rate_n_per_mm=round(k, 4),
                over_centre_offset_mm=KEEPER_OVER_CENTRE_MM,
                hold_n=round(hold, 4), release_n=round(hold, 4))


def cell_fit() -> dict:
    """Two-axis geometry: does the pawl + keeper fit the 5.08 mm cell?

    design calculation re-profile (residual-KEEPER): the keeper was 1 line (0.45 mm) and sat
    BEHIND the pawl in the pitch direction (X), so the X-band held pawl+keeper.
    Re-profiling it to 2 lines (0.90 mm) there would consume the free band
    (worst-case gap 0.02 mm < 0.20 mm). The keeper is therefore re-profiled into
    the ROW direction (Y), beside the pawl, where the cell has room: the X-band
    then holds only the pawl, and the Y-band holds pawl+keeper. Both axes clear.

    X-band free width = PITCH - 2R (between rotor edges).
    Y-band free width = PITCH - 2R too (row pitch = column pitch), but the
    pawl+keeper pair is 0.70 + 0.90 = 1.60 mm, inside 2.08 mm.
    """
    rotor_dia = 2.0 * ROTOR_RADIUS_MM
    free_band = PITCH_MM - rotor_dia
    # X: pawl only (keeper moved to Y).
    stack_x = PAWL_T_MM
    stack_x_worst = stack_x + 2.0 * DIM_ACCURACY_MM
    # Y: pawl + keeper side by side.
    stack_y = PAWL_W_MM + KEEPER_LEAF_T_MM
    stack_y_worst = stack_y + 2.0 * DIM_ACCURACY_MM
    # Bounding (worst) axis for the crosstalk gate.
    worst_gap = min(free_band - stack_x_worst, free_band - stack_y_worst)
    return dict(
        pitch_mm=PITCH_MM, rotor_dia_mm=round(rotor_dia, 3),
        free_band_mm=round(free_band, 3),
        keeper_direction="Y (row direction), beside the pawl",
        x_stack_nominal_mm=round(stack_x, 3),
        x_stack_worst_mm=round(stack_x_worst, 3),
        x_tip_gap_worst_mm=round(free_band - stack_x_worst, 3),
        y_stack_nominal_mm=round(stack_y, 3),
        y_stack_worst_mm=round(stack_y_worst, 3),
        y_tip_gap_worst_mm=round(free_band - stack_y_worst, 3),
        in_band_stack_nominal_mm=round(stack_y, 3),
        in_band_stack_worst_mm=round(stack_y_worst, 3),
        stack_inside_band=bool(stack_y_worst <= free_band),
        tip_gap_worst_mm=round(worst_gap, 3),
        fits_worst_case=bool(worst_gap > 0.0),
    )


def neighbour_crosstalk() -> dict:
    """A dropped-out pawl carries zero rack force; cross-talk is a gap."""
    drift = 2.0 * DIM_ACCURACY_MM
    gap = cell_fit()["tip_gap_worst_mm"]
    return dict(dropped_pawl_rack_force_n=0.0, keeper_holds_pawl_clear=True,
                detent_lash_mm=round(drift, 3), worst_tip_gap_mm=gap,
                gap_after_lash_mm=round(gap - drift, 3),
                no_contact=bool(gap - drift > 0.0),
                note="a dropped-out pawl is held clear of the rack by its "
                     "keeper and carries zero drive force; the shared bar "
                     "transmits no per-cell load to a dropped pawl, so "
                     "neighbour cross-talk is a geometry gap, not a force.")


def writer_budget() -> dict:
    kh = keeper_hold()
    pawl = pawl_spring()
    friction = MU_PLA_MID * pawl["force_n"]
    required = kh["release_n"] + friction
    return dict(keeper_release_n=kh["release_n"],
                pawl_normal_n=pawl["force_n"],
                guide_friction_n=round(friction, 4),
                required_solenoid_n=round(required, 4),
                available_solenoid_n=WRITER_FORCE_N,
                margin=round(WRITER_FORCE_N / required, 4) if required else None,
                pass_gate=bool(WRITER_FORCE_N >= required))


def bank_drive_load(rows_in_bank: int) -> dict:
    """Force to stroke a bank of COLS*R ganged pawls through the rack."""
    pawl = pawl_spring()
    per_pawl = pawl["force_n"] + WRITE_LOAD_N
    n = COLS * rows_in_bank
    total = n * per_pawl
    req = total / BUS_EFFICIENCY
    avail = BANK_MOTORS * (BANK_MOTOR_TORQUE_NM * 1000.0) / BANK_PINION_RADIUS_MM
    return dict(rows_in_bank=rows_in_bank, n_pawls=n,
                per_pawl_n=round(per_pawl, 4), total_rack_n=round(total, 3),
                bus_efficiency=BUS_EFFICIENCY, bank_motors=BANK_MOTORS,
                required_motor_force_n=round(req, 3),
                available_motor_force_n=round(avail, 3),
                margin=round(avail / req, 3), pass_gate=bool(avail >= req))


def latch_holding_vs_service() -> dict:
    return dict(terrain_carried_by="rotor hard stop / follower toe (K1 path)",
                latch_load_in_service_n=0.0,
                k1_service_bounding_n=K1_SERVICE_BOUNDING_N,
                k1_service_distributed_n=K1_SERVICE_DISTRIBUTED_N,
                inherits_k1_bound=True,
                note="the latch is dormant while the machine holds terrain "
                     "load; it only holds the pawl clear of the rack during an "
                     "unloaded write. The K1 bound is inherited, not changed.")


def endurance(rows_in_bank: int) -> dict:
    steps_per_group = LEVELS - 1
    groups = math.ceil(ROWS / rows_in_bank)
    strokes_per_map = groups * (steps_per_group + 1)  # +1 reset pass
    strain = ENDURANCE_LEAF_STRAIN
    seen = [(eps / strain) ** ENDURANCE_BASQUIN_M * 1e6
            for eps in ENDURANCE_EPS_SPAN]
    return dict(rows_in_bank=rows_in_bank, groups=groups,
                strokes_per_map=strokes_per_map,
                leaf_strain=round(strain, 6),
                cycles_span=[round(min(seen), 1), round(max(seen), 1)],
                maps_span=[round(min(seen) / strokes_per_map, 1),
                           round(max(seen) / strokes_per_map, 1)],
                label=">=1e6, order unknown")


def timing(rows_in_bank: int) -> dict:
    """Full-map time for the R-row register, built from the mechanism cycle.

    The writer carriage must set every column in the group (COLS * R), so the
    number of station moves scales with R (this is the term design calculation omitted).

    design calculation timing note: the pass is *angular* -- the crank turns LEVEL_ANGLE_DEG
    (72 deg) per level regardless of the rack pitch. The rack re-dimension
    (0.60 -> 1.00 mm pitch, RACK_STROKE_MM = 1.00 mm) changes the per-stroke
    *linear* travel, not the crank angle, so the select/reset times are
    UNCHANGED. It is carried in `rack_stroke_mm` for traceability.
    """
    groups = math.ceil(ROWS / rows_in_bank)
    cells_per_group = COLS * rows_in_bank
    stations = math.ceil(cells_per_group / WRITERS)
    writer_s = stations * WRITER_SETTLE_S
    select_s = (LEVELS - 1) * LEVEL_ANGLE_DEG / BANK_CRANK_DEG_S
    reset_s = LEVEL_ANGLE_DEG / BANK_CRANK_DEG_S
    per_group = writer_s + select_s + reset_s
    full = (tc.fixed_s() + (groups - 1) * tc.index_s() + groups * per_group)
    return dict(rows_in_bank=rows_in_bank, groups=groups,
                cells_per_group=cells_per_group, stations=stations,
                writers=WRITERS,
                rack_stroke_mm=RACK_STROKE_MM,
                crank_deg_per_level=LEVEL_ANGLE_DEG,
                writer_s_per_group=round(writer_s, 4),
                select_pass_s=round(select_s, 4), reset_pass_s=round(reset_s, 4),
                per_group_s=round(per_group, 4),
                full_map_s5r_s=round(full, 3),
                full_map_s5_reference_s=round(tc.full_map_s(400), 3),
                clears_30s=bool(full < 30.0),
                margin_to_30s_s=round(30.0 - full, 3))


def delivered(parts_usd: float) -> float:
    return round(parts_usd * UPLIFT, 2)


# --- Purchased driver channels for the S5-R actuator block -------------------
# The fixed no-channel base (FIXED_PARTS_NO_CHANNEL) has BOTH the 80-motor
# line AND the 80-channel TB6612 driver block removed, by the nx52 contract:
# "every option declares its own channel cost exactly once (no double-count)".
# The S5-R block therefore OWNS its channels:
#   * 2 bank steppers (bipolar) need 2 H-bridge channels. Priced conservatively
#     at 1 dual TB6612 IC per motor (2 ICs) -- the working figure used by the
#     design calculation ratification; the optimistic 1-IC shared case is carried alongside.
#   * 40 writer solenoids are ON/OFF loads: a ULN2803-class 8-channel darlington
#     (~$0.30) switches 8 each -> 5 chips. No H-bridge is needed (design calculation).
# These are marginal-bought-channel parts; the `Custom driver PCBs and passives`
# line stays in the fixed base but was sized for the 80-motor H-bridge head, so
# pricing the S5-R channels explicitly makes the BOM auditable.
BANK_ICS_WORKING = BANK_MOTORS          # 1 dual H-bridge IC per bank motor
BANK_ICS_OPTIMISTIC = 1                 # both motors share one dual IC
BANK_IC_USD = BANK_DRIVER_USD         # $0.7955, LCSC C88224 (E1 source)
WRITER_CHIP_USD = 0.30                  # ULN2803-class 8-ch darlington
WRITER_CHIPS = (WRITERS + 7) // 8       # 5 chips for 40 writers
# The shared drive bar is a SOURCED steel rod (design calculation/design calculation), not a printed
# part. One 6 mm x 406.4 mm ground steel rod is a single commodity line; the
# allowance is a stated sourced-class figure (rod stock ~$6/m retail, cut).
STEEL_ROD_USD = 3.00                    # sourced-class allowance, 1 rod


def bom(rows_in_bank: int) -> dict:
    bank_motors = BANK_MOTORS
    motor_usd = 12.00
    writers = WRITERS
    writer_usd = 2.50
    actuator_parts = bank_motors * motor_usd + writers * writer_usd
    # Channels the S5-R block owns (priced exactly once; not in the fixed base).
    channel_parts = round(BANK_ICS_WORKING * BANK_IC_USD
                          + WRITER_CHIPS * WRITER_CHIP_USD, 2)
    channel_parts_optimistic = round(BANK_ICS_OPTIMISTIC * BANK_IC_USD
                                     + WRITER_CHIPS * WRITER_CHIP_USD, 2)
    # Sourced drive rod (replaces the printed 3x2 placeholder; design calculation).
    rod_parts = STEEL_ROD_USD
    # The design calculation claim (channels unpriced, rod unpriced).
    parts_claim = FIXED_PARTS_NO_CHANNEL + actuator_parts
    delivered_claim = delivered(parts_claim)
    # design calculation ratified claim (channels priced, rod unpriced) and honest total.
    parts_no_rod = round(parts_claim + channel_parts, 2)
    delivered_no_rod = delivered(parts_no_rod)
    parts = round(parts_no_rod + rod_parts, 2)
    d = delivered(parts)
    return dict(rows_in_bank=rows_in_bank,
                fixed_no_channel_parts_usd=FIXED_PARTS_NO_CHANNEL,
                bank_motors=bank_motors, writers=writers,
                actuator_parts_usd=round(actuator_parts, 2),
                actuator_count=bank_motors + writers,
                bank_ic_count=BANK_ICS_WORKING, bank_ic_unit_usd=BANK_IC_USD,
                writer_chip_count=WRITER_CHIPS,
                writer_chip_unit_usd=WRITER_CHIP_USD,
                channel_parts_usd=channel_parts,
                channel_parts_optimistic_usd=channel_parts_optimistic,
                steel_rod_count=1, steel_rod_unit_usd=STEEL_ROD_USD,
                rod_parts_usd=round(rod_parts, 2),
                parts_claim_usd=round(parts_claim, 2),
                delivered_claim_usd=delivered_claim,
                parts_no_rod_usd=parts_no_rod,
                delivered_no_rod_usd=delivered_no_rod,
                parts_usd=round(parts, 2), delivered_usd=d,
                ceiling_usd=COST_CEILING_USD, clears=bool(d < COST_CEILING_USD),
                margin_usd=round(COST_CEILING_USD - d, 2),
                note="actuator count is 2 bank motors + %d writer solenoids; "
                     "the 80-motor head and its 80-channel driver block are "
                     "removed, but the S5-R block's OWN %d bank H-bridge IC(s) "
                     "and %d writer darlington chip(s) are priced here "
                     "(design calculation; no double-count). design calculation adds the 1 sourced "
                     "steel drive rod d=6 (priced here, not previously in the "
                     "printed-placeholder lines). Sourced point-in-time prices."
                     % (writers, BANK_ICS_WORKING, WRITER_CHIPS))


def decide(rows_in_bank: int = ROWS_IN_BANK) -> dict:
    fit = cell_fit()
    xtalk = neighbour_crosstalk()
    wb = writer_budget()
    bd = bank_drive_load(rows_in_bank)
    lat = latch_holding_vs_service()
    tm = timing(rows_in_bank)
    bom_ = bom(rows_in_bank)
    gates = {
        "G1_cell_fit_worst_case": fit["fits_worst_case"],
        "G2_no_neighbour_crosstalk": xtalk["no_contact"],
        "G3_writer_force": wb["pass_gate"],
        "G4_bank_drive_force": bd["pass_gate"],
        "G5_latch_inherits_K1": lat["inherits_k1_bound"],
        "G6_full_map_under_30s": tm["clears_30s"],
        "G7_cost_under_500": bom_["clears"],
    }
    all_pass = all(gates.values())
    return dict(
        rows_in_bank=rows_in_bank,
        evidence_class="CAD geometry + CALCULATION over sourced FDM process "
                       "limits and sourced actuator ratings; no print, no "
                       "purchase, no measurement (design calculation)",
        gates=gates, all_mechanical_gates_pass=bool(all_pass),
        promotable=bool(all_pass),
        residual_uncertainty=[
            "G8 cycle life is reported, not gated: '>=1e6, order unknown' on "
            "the same design calculation FDM constants as every other printed leaf.",
            "The bank crank speed (720 deg/s) and writer settle (0.05 s) are "
            "assumptions; the time gate is conditional on them, exactly as "
            "S5's K6 is conditional on its dwell.",
            "As-printed friction mu, gate/tip sharpness and leaf creep remain "
            "measurement-only (K2/K11 class), unchanged by this pivot.",
            "A missed keeper set is a silent row error, the same failure class "
            "as S5's missed step. No per-cell feedback exists (R1 unchanged).",
            "The R-row bar drive and the writer-carriage indexing are "
            "kinematically plausible but not CAD-interference-checked in a "
            "full multi-row assembly; only the unit cell is modelled here.",
        ],
        verdict=("PROMOTE_TO_08" if all_pass else "REJECT"),
    )


def screen(rows_in_bank: int = ROWS_IN_BANK) -> dict:
    return dict(
        evidence_class="CAD + CALCULATION (design calculation); no print/purchase/measurement",
        cell_fit=cell_fit(),
        neighbour_crosstalk=neighbour_crosstalk(),
        writer_budget=writer_budget(),
        bank_drive_load=bank_drive_load(rows_in_bank),
        latch_vs_service=latch_holding_vs_service(),
        endurance=endurance(rows_in_bank),
        timing=timing(rows_in_bank),
        bom=bom(rows_in_bank),
        sensitivity=sensitivity(rows_in_bank),
        decision=decide(rows_in_bank),
    )
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

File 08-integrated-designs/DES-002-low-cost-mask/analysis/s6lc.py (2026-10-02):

"""s6lc; CAD/calculation source, no physical validation."""
from __future__ import annotations

import json
import math
from pathlib import Path

HERE = Path(__file__).resolve().parent
REPO = HERE.parent.parent

# ---------------------------------------------------------------------------
# Product gates (unchanged from the programme; 02-design-criteria).
# ---------------------------------------------------------------------------
PITCH_MM = 5.08
ROWS = 80
COLS = 80
CELLS = ROWS * COLS                      # 6400
LEVELS = 5
LEVEL_MM = 10.0                          # 10 mm per level -> 4 strokes = 40 mm
TRAVEL_MM = (LEVELS - 1) * LEVEL_MM      # 40.0
PITCH_CLEARANCE_MM = 1.48                # S1-sourced lane (body 3.60 + 1.48)
COLUMN_BODY_MM = PITCH_MM - PITCH_CLEARANCE_MM   # 3.60 mm square (S1 coupon)
ACTIVE_MM = ROWS * PITCH_MM              # 406.4 mm
TIME_GATE_S = 30.0
COST_GATE_USD = 250.0                    # design calculation: purchased, excl. printed
UPLIFT = 1.10 + 0.06                     # repo additive delivered uplift

# ---------------------------------------------------------------------------
# Banking (S1-B): 8 banks of 10 rows = 800 cells. Bounds release force.
# ---------------------------------------------------------------------------
ROWS_PER_BANK = 10
BANKS = ROWS // ROWS_PER_BANK            # 8
CELLS_PER_BANK = COLS * ROWS_PER_BANK    # 800

# ---------------------------------------------------------------------------
# Global-stroke / banked-reset timing (mechanism cycle, every term explicit).
#
# DESIGN CHOICE (design calculation): the platen strokes the WHOLE 80x80 board at once --
# that is the point of a broadcast architecture. All 6,400 cells see all four
# 10 mm strokes. The MASK (punched card) decides which cells advance, so no
# per-bank platen is needed for writing. Only the RESET is banked: eight
# staggered release combs trip the pawls one bank at a time, which is what
# bounds the worst-case simultaneous release force (S1-B). This is both faster
# and force-feasible than a serial per-bank platen (see sensitivity()).
# ---------------------------------------------------------------------------
PLATEN_SPEED_MM_S = 20.0                 # sourced-class lead-screw axis speed
STROKE_MM = LEVEL_MM                     # 10 mm broadcast stroke
SETTLE_S = 0.15                          # mechanism settle at stroke top (assumption)
RETURN_S = 0.20                          # platen returns to datum per stroke (assumption)
RESET_S = 0.50                           # release comb + drop per BANK (assumption)
STROKES = LEVELS - 1                     # 4 global broadcast strokes
STROKES_PER_BANK = STROKES
# design calculation/design calculation Attack 4/6: the previously-unpriced overhead terms.
MASK_INDEX_S = 0.25                      # mask-gate re-index between strokes (assumption)
CARRIAGE_SPEED_MM_S = 100.0              # reset carriage traverse speed (assumption)
BANK_PITCH_MM = ACTIVE_MM / BANKS        # 50.8 mm from bank to bank
CARRIAGE_TRAVERSE_S = BANK_PITCH_MM / CARRIAGE_SPEED_MM_S  # 0.508 s per bank gap

# ---------------------------------------------------------------------------
# Reset-carriage axis (design calculation/91 Attack 5: previously ungated).
# The carriage hauls one banked release comb at a time: load = banked release
# force, through the same <=2 mm lead, on the $8 small stepper.
# ---------------------------------------------------------------------------
RESET_MOTOR_TORQUE_NM = 0.16             # sourced-class 42 mm small stepper (~$8)

# ---------------------------------------------------------------------------
# Sourced process / material limits (as used across Test11/Test12).
# ---------------------------------------------------------------------------
MIN_FEATURE_MM = 0.44                    # 1 extrusion line @ 0.4 mm nozzle
MIN_WALL_MM = 0.88                       # 2 lines, robust
PLA_E_MPA = 1500.0                       # sourced modulus range 700-2500, midpoint
MU_PLA_MID = 0.35
COLUMN_MASS_G = 1.0                      # printed 4.68 x 4.68 x 44 mm column (calc)
PAWL_RELEASE_N_DESIGN = 0.234            # S1 study break-even; design under it
COLUMN_SERVICE_LOAD_N = 3.27             # [design calculation] K1 bounding terrain load/column
PLA_COMPRESS_MPA = 50.0                  # sourced-class PLA compressive strength


# ---------------------------------------------------------------------------
# Cell / pawl geometry (printed).
# ---------------------------------------------------------------------------
def _cantilever_rate_n_per_mm(t: float, w: float, l: float,
                              e_mpa: float = PLA_E_MPA) -> float:
    i = w * t ** 3 / 12.0
    return 3.0 * e_mpa * i / l ** 3


PAWL_T_MM = 0.90                         # ROOT block thickness (frame-anchored, outboard)
# design calculation (A2) fix: the bending LEAF is PAWL_T/2 = 0.45 mm (scad/s6lc_machine.scad),
# not the 0.90 mm root block. Using the root section overstated k by 8x.
PAWL_LEAF_T_MM = 0.45                    # LEAF thickness in the bending axis (enters lane)
PAWL_W_MM = 1.20                         # width in Y
PAWL_L_MM = 8.00                         # Z cantilever length (long -> soft)
PAWL_DEFLECTION_MM = 0.25                # cam-over relief at a pocket
# design calculation (A1) fix: the cell OWNS only half the inter-body gap (0.74 mm); the part
# that enters the pitch band (the leaf, 0.45 mm) must fit THAT, not the whole 1.48.
LANE_BLEED_MM = 0.20
LANE_RAIL_MM = 0.48
OWNED_LANE_MM = PITCH_MM / 2 - COLUMN_BODY_MM / 2       # 0.74 mm
# design calculation (A6): reliability gate constants.
PER_CELL_ERROR_BUDGET = 1.570e-6         # q for a 99% map at 6,400 cells
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

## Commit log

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2026-09-28 Add Test11 falsification library and shared isolation-rig protocol
    Adversarial layer for survivors S1-S5 plus the cross-cutting reliability
    and process-variation gates. No physical evidence is claimed.
    - falsification_register.csv (generated): cheapest rejection test, gates,
    cycle counts, pass/fail consequences per survivor claim.
    - reliability.py + checks.py: per-cell -> 6400-cell map probability,
    regional scaling, return margin, tolerance yield. Re-derives Test09's
    52.7% / 93.8% / 1.57e-6 / 1.91e6 figures as CI regressions.
    - isolation_rig_protocol.md + j2_isolation_rig.scad + measurements/isolation.csv:
    the architecture-agnostic Q5 regional-isolation rig, buildable on the X1C,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
    [falsification_register.csv, isolation.csv, j2_isolation_rig.scad]
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2026-09-28 Add Test11 selector fan-out coupon at final 5.08 mm pitch
    Re-derive the printable sliding-gate latch from legacy Test07 at the final
    5.08 mm pitch used by the D&D battle-map target, and test the three decisive
    questions for the S3/S4 shared-drive family with the cheapest possible
    artifacts:
    - coupon_geometry.py: stdlib analytical model (row-band budget, radial blade
    overreach, shared-stroke partition, actual tooth overlap, retaining-face
    shear, per-column gate bus timing).
    - checks.py: seven falsifiable PASS/FAIL gates; three currently FAIL.
    - selector_coupon.scad: final-pitch 2x4 latch cluster, interchangeable
    carriers, sliding gate piece and a separate 5 N retention abuse tile.
    - RE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
    [passive.csv, results_summary.csv, selector_coupon.scad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]
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2026-09-28 Test11: runnable isolation-rig gate engine, print-ready fixture, measurement plan
    Add the executable half of the J2 isolation protocol requested after the
    falsification library landed:
    - isolation_rig_runner.py: gate engine over measurements/isolation.csv that
    emits GO/KILL/INCONCLUSIVE per survivor with repeat-count guards. --selftest
    exercises every gate on SYNTHETIC rows (CI-wired); --validate checks schema.
    reliability_consequence() bridges a counted coupon run to P(perfect map).
    - measurement_plan.md: decision table for peak vertical/lateral motion,
    miniature move/tip, seam, drift and regional timing, plus the reliability
    bridge and per-survivor go/kill consequence.
    - j2_isol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
    [j2_isolation_rig.scad]
2026-09-28 Add printable 5.08 mm-pitch S1 threshold-ratchet coupon + coupon checks
    Reproduces the previously-blocked Test11 S1/S2 rejection screen on the current
    main (the prior patch did not apply after the parallel Test11 shared-drive
    merge) and adds the missing printable artifact.
    New in this commit:
    - build_coupon.py emits slicer-ready binary STLs directly from axis-aligned
    boxes (no CAD kernel / OpenSCAD needed) plus params.json, manifest.json and
    coupon.scad.
    - coupon_checks.py asserts the 5.08 mm pitch budget closes and validates STL
    headers/counts, non-degenerate triangles and nonzero extents.
    - README records a hostile review of the first coupon (floating 0.30 mm plate,
    unrooted pawl,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
    [coupon.scad, coupon_assembly.stl, coupon_column.stl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]
2026-09-28 Test11 J2: fix buried fixture socket; add CAD-render gate
    The holder's interchangeable-fixture socket was implemented as a pocket
    inside the frame's already-solid bottom, so it was buried in plastic and
    the export was two overlapping CSG volumes. The socket is now a real open
    recess cut from the floor top.
    Rendered all six J2 parts with OpenSCAD 2021.01 (aarch64) and added a
    socket-exposure probe to check_fixture.py so the bug cannot return
    silently. Also fixed a dangling print_plan.md reference.
    Evidence: CAD render (not a print). OpenSCAD absent from the default
    agent PATH; aarch64 build supplied locally for this run.
    [j2_isolation_rig.scad]
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2026-09-28 Add Test11 shared-drive family machines and S5 gate list
    Specify complete S3 (multi-row mechanical DMA head) and S4 (distributed
    passive tiles on a shared bus) machines with real component counts, and
    reduce S5 to five explicit open gates with per-gate qualifying coupons.
    - S3: bit-plane cam programmer, 41 head motors, zero bought per-channel
    selectors, calculated 25.20 s full-map schedule, printable fan-out pitch
    as the primary killer.
    - S4: 64 tile clutches must be printed (64 x $6 = $384 bought is
    unaffordable); dominant distinct risk is correlated bus backlash.
    - S5: five gates all open; reproduces the $1.058/motor boundary that does
    not fit $500 with 20% contingency.
    - Adds mod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
    [selector_fanout_coupon.scad]
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2026-09-28 Add runnable T11-A fit-coupon gate engine and run-record scaffold
    DND-21 asks to print and measure the T11-A S3 selector fan-out coupon. No
    fabrication hardware is reachable from the agent runtime (no printer, slicer
    host, or fabrication bridge), so the physical A1-A4 print and caliper/microscope
    M1-M6 pass cannot be executed by any agent. This change ships the executable
    half: a gate engine that mechanically applies the protocol's pass/kill gates and
    decision tree the moment a real row is entered, plus the dated run-record schema.
    - t11a_fit_check.py: reads runs/t11a_measurements.csv, scores M1-M6 per print,
    and resolves the protocol decision tree across the 0.4 mm baseline and the
    0.2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
    [t11a_measurements.csv]
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2026-09-28 DND-28: re-scope T11-A + J2 physical gates to analytic/simulation gates
    Replaces the now-impossible physical print/measure gates of DND-21 (T11-A S3
    selector fan-out coupon) and DND-14 (J2 isolation rig) with the strongest
    non-physical evidence gates that can still reject the candidate architectures.
    No physical print tests are performed (DND-27).
    A. T11-A analytic gate (06-experiments/test11_shared_drive_gate_analysis/analytic/)
    * Sourced FDM printability screen (min wall ~1.05x nozzle, min slot ~1x
    nozzle; free-gap and pivot floors labelled as assumptions).
    * Worst-case + Monte Carlo tolerance stack-up for min web, pivot free play,
    land reach, lateral clearance and bbox.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
    [isolation_analytic.csv, t11a_analytic_measurements.csv]
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2026-09-28 DND-4: designed pivot clearance closes the S3 selector fan-out gate analytically
    The S3 Step-4 selector fan-out gate could only reach INCONCLUSIVE because
    protocol gate M3 (finger pivot free after print) was unmodelled: the coupon
    printed its pivot in place with no designed radial clearance.
    Redesign the coupon pivot as a designed journal fit:
    - add PIVOT_CLR = 0.20 mm/side, giving socket bore PIVOT_SOCKET_D = 1.20 mm
    and a 0.40 mm diametral free play. This clears the 0.20 mm free-gap floor
    with +0.08 mm worst-case margin (boss high / socket low).
    - cut the base socket bores in selector_fanout_coupon.scad; parity update to
    the stdlib make_coupon_stl.py generator.
    - model the boss and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
    [coupon_assembled.stl, coupon_base.stl, selector_fanout_coupon.scad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]
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2026-09-28 DND-4: close M4 land reach analytically and fix two validator mis-scopes
    M4 land reach was the last thin S3 gate term and was reported as a
    worst-case -0.05 mm margin, which came from comparing the bank land height
    against an arbitrary +/-0.20 mm window around a 0.50 mm protocol artefact.
    That is not the physical quantity: what matters is whether the cam land
    produces a finger angular throw inside the rocker's usable range.
    - analytic/t11a_analytic_gate.py: model M4 as throw = asin(land/FINGER_H) with
    LAND_H_NOMINAL = 0.90 mm (16.3 deg), plus an explicit contact floor. Worst
    case margin is now +0.35 mm, MC pass 1.0000 (was 0.9077). Add an
    ANALYTIC_FAIL_LAND_REACH verdict path.
    - t11a_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
    [t11a_analytic_measurements.csv]
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2026-09-29 DND-54: S5-R register analytic + CAD dropout-latch model (promote S5-R)
    Define the S5-R shared-drive programmable register concretely and decide it
    with the DND-27 evidence classes (CAD + calculation; no print, no purchase).
    - New model 06-experiments/test12_winner_convergence/s5r_register.py + checks:
    shared oscillating drive bar, printed drive pawl, bistable over-centre keeper
    latch with a 5-position gate, writer solenoid bank.
    - DND-54 correction to DND-52: the bank bar spans R rows in depth at no pitch
    penalty. R=1 (DND-52 option-1), counted honestly per row, is >=36 s; the R=4
    bank with 40 writers + 2 bank motors is the design point.
    - All seven analytic gates pass: cell fit, z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
    [s5r_register.scad]
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2026-09-29 DND-54: price the S5-R block's own channels in the model ($401.12 honest total)
    Fold the DND-56 ratification finding into s5r_register.bom(): the fixed
    no-channel base removes both the 80-motor line and the 80-channel TB6612
    driver block, so per the nx52 contract the S5-R block must declare its
    own channels exactly once. bom() now charges 2 bank H-bridge ICs ($1.59)
    + 5 ULN2803-class writer chips ($1.50) = $3.09 parts, so its honest
    delivered total is $401.12 (working) while the channels-unpriced DND-54
    claim reproduces as delivered_claim_usd = $397.53. G7 still passes
    ($98.88 under the $500 ceiling; $1.12 over the <$400 ideal band).
    - s5r_register.py: channel constants + priced lines + cla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
    [s5r_register.py]
2026-09-29 DND-55: S5-R R=4 multi-row bank assembly (bar torsion + comber/carriage envelopes)
    CAD-model the R=4 bank that DND-54 left un-modelled (residual R-DND54-4) and close
    its assembly-level geometry analytically, per DND-27 (no print, no purchase, no
    measurement).
    - s5r_bank.py: parametric bar-torsion model, candidate sections, clearance
    stack-ups, envelope fit, real-OpenSCAD CAD harness, decision + sensitivity.
    - s5r_bank.scad: R=4 columns + racked bar + reset comber + writer-carriage sweep
    envelope, with five scoped interference queries (all empty).
    - s5r_bank_checks.py: 16 regression + honesty gates (SCAD/model sync, refuted
    placeholder bar, steel-rod pass, honest assembly verdict, evid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
    [s5r_bank.scad]
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2026-09-29 DND-58: reconcile the corrected 1.00 mm rack pitch + steel drive rod into S5-R
    Apply the DND-55 bank close-out corrections at the register level (residual
    R-DND55-4), per DND-27 (no print, no purchase, no measurement).
    - s5r_register.scad / s5r_register.py: rack re-dimensioned to pitch 1.00 /
    tooth 0.50 mm (the 0.60/0.45 rack leaves a 0.15 mm gap that fuses); per-stroke
    advance RACK_STROKE_MM = 1.00 (keyed to the pitch, was the 0.45 tooth height);
    drive bar declared and rendered as a sourced steel rod d=6 (BAR_D_MM), not a
    printed 3x2 placeholder.
    - Timing unchanged at 24.62 s: the bank pass is angular (72 deg/level), so the
    linear rack pitch does not enter it; timing() reports ra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
    [s5r_register.scad]
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2026-09-29 DND-59: retire the agent-reachable S5-R residuals
    Retires/bounds the five agent-reachable S5-R residuals on the DND-27
    evidence classes (CAD + CALCULATION + sourced). No print, no purchase.
    1. R-DND54-KEEPER (keeper leaf 1 line RISK): re-profiled 0.45 -> 0.90 mm
    (2 extrusion lines; register printability RISK -> PASS). The hold is
    moved off a tolerance-fragile bending-spring offset onto a hard printed
    shoulder in compression (144-324x the pawl push-out). The keeper is
    also moved into the row (Y) axis so it does not consume the pitch band
    (X gap 0.98 mm, Y gap 0.28 mm worst case).
    2. R-DND54-6 (writer force): re-derived bottom-up (0.2425 N) and cleared
    by the sourced 5 V pus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
    [s5r_bank.scad, s5r_register.scad]
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2026-09-29 DND-60: S5-R complete printable fabrication package (part set + manifests)
    Produce the board-usable printable package for the promoted S5-R machine
    (shared-drive programmable rotary register, R=4), closing the DND-57 gap that
    08-current-design was a definition, not a printable package.
    - Complete real-OpenSCAD printed-part set: 14 distinct parts, 25,661 pieces,
    in 08-current-design/fabrication/scad (single constants include so the
    package cannot drift from the promoted model).
    - 14 rendered, watertight, bed-fitting STLs in fabrication/stl (CAD witnesses).
    - Print manifest (qty/material/nozzle/layer/orientation/supports/sourced limit/
    est. mass+time) and assembly manifest (exploded ord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
    [assembly_manifest.csv, bank_drive_housing.stl, cell_cartridge.stl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]
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2026-09-29 DND-72: ultra-low-cost S5-R variant (<$250) — infeasibility proof + break-even + CAD
    Negative result: the S5-R fixed no-channel purchased base alone is $218.70
    parts -> $253.69 delivered, already over the $250 target with zero actuators.
    An exhaustive 570-point sweep of the (R, writers, bank-motors) lever space finds
    no sub-$250 configuration; the cheapest requirement-preserving point is
    R6-W20-M2 at $345.90 delivered / 29.987 s. Break-even ~$346; gap $95.90.
    - 09-low-cost-variant/: analytic model (s5r_ultra.py) + 19 CI checks,
    real-OpenSCAD unit cell + R=6 bank cross-section, watertight STLs,
    render tool, README.
    - 07-evidence-and-decisions/dnd72-low-cost-variant.md: ADR with sourced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
    [cell.stl, keeper.stl, pawl.stl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]
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2026-09-29 DND-72: consolidate to one ultra-low-cost track — select S6-LC, keep trim negative result
    Reconciles the two divergent DND-70 workstreams onto the single authoritative
    DND-72 node (CEO consolidation direction):
    - Fold the DND-71 S6-LC machine definition in under 09-low-cost-variant/s6lc/.
    S6-LC = S1-B broadcast threshold ratchet: passive printed pawl memory, no
    per-cell/per-row bought actuator, off-line punched-card per-bank mask gate,
    one lead-screw lift stepper. $139.77 parts / $162.13 delivered / 7.4 s,
    all six gates pass (29/29 checks).
    - Retain the DND-72 negative-result model unchanged as the proof that trimming
    the S5-R architecture cannot reach $250 (fixed base $218.70 p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
    [bom_s6lc.csv, s6lc_bank.stl, s6lc_cell.stl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]
2026-09-29 DND-76: ultra-low-cost cell/mechanism primitives (<$250) — four divergent primitives + CAD
    Adds 09-lowcost-alternative/primitives/ attacking the four S6-LC weak points
    named in DND-76. Every primitive is 100% printed: zero bought selectors,
    zero bought clutches, zero extra motors.
    P1 friction-independent bistable over-centre latch (release-force spread)
    P2 printed 4-plane louvre comb stack as the mask medium (correlated 80-cell failure named)
    P3 relieved pocket throat + V-guide at 3.60 mm body / 1.48 mm lane
    P4 single-actuator banked reset (reset bar rides the common platen)
    Full system accounting: 13.0 s full map, $170.17 worst-case purchased,
    12,800 printed column/pawl + 32 combs + 8 c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
    [mask_comb.scad, reset_bar.scad, s6lc_cell.scad]
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2026-09-29 DND-76: real OpenSCAD renders + watertight mesh validation
    - Parameterise the three SCAD files by -D part=<key>.
    - render_primitives_cad.py now mesh-validates every single-manifold part
    (bbox / 256 mm bed / watertight via trimesh or a stdlib edge check) and
    hard-fails without OpenSCAD; multi-body 'cell' is a viewing assembly.
    - Commit 8 watertight STLs. Verified this run: column 302 tris watertight,
    every part inside the bed.
    [cell.stl, column.stl, latch.stl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]
2026-09-29 DND-72: fold DND-75 divergent machines onto the authoritative track
    Completes the consolidation: the DND-75 inventor divergence (A1 single-shaft cam
    $67.63, A2 hand-crank/punched-tape $49.76, A3 S1-B banked broadcast $114.02) is
    brought onto the DND-72 branch under 09-low-cost-variant/divergent/, replacing the
    duplicate 09-lowcost-alternative/ on the superseded DND-71 branch.
    - Merge the superset analytic_printability.py (adds check_media_cell +
    check_a1_cam_cell routes; retains the s5r_ultra_cell route) so both the trim
    cell and the divergent cells route correctly.
    - CI: add the folded divergent-machines gate.
    - ADR: add the DND-75 divergence table; umbrella README lists divergent/.
    -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
    [a1_cam_cell.scad, a2a3_media_cell.scad]
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2026-09-29 DND-94: reconcile duplicate 09-* low-cost roots (fold DND-76 primitives)
    Repo hygiene only; no engineering numbers change.
    - Fold 09-lowcost-alternative/primitives/ into the authoritative
    09-low-cost-variant/primitives/ and delete the duplicate 09-* root.
    - Fix every stale path reference: 09-lowcost-alternative/primitives/* ->
    09-low-cost-variant/primitives/*, and the non-existent
    09-lowcost-alternative/analysis/s6lc.py + PR #70/feat/... refs ->
    ../s6lc/analysis/s6lc.py.
    - Update .github/workflows/ci.yml step/run paths to the folded location.
    - Update 09-low-cost-variant/README.md index and the DND-72 synthesis ADR row
    that named the retired root.
    - Add a supporting-material banne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
    [cell.stl, column.stl, latch.stl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]
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2026-09-29 DND-93: fix S6-LC lift-axis G3 (global board) + honest allowances; G6 fails
    The DND-74/DND-91 audit broke G3: lift_axis() sized the platen torque on
    one bank (800 cells) while the mechanism writes the whole 6,400-cell board
    in one global stroke. Corrected to all 6,400 cells at the model's own
    0.4 N/cell: 2,560 N -> 1.6297 N*m, so a NEMA23-class motor (2.2 N*m) is
    required; G3 now passes at 1.35x.
    Same pass, the audit's bounded findings:
    - Replace the circular 296 N ceiling with an independent comb-tooth bending
    limit (PLA 1.6x0.88x1.0, 50 MPa/SF2 -> 413 N).
    - Add a reset-carriage torque gate G7 (128.2 N -> 0.082 N*m vs 0.16 N*m).
    - Price the mask-index and carriage-traverse timing terms (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
    [bom_s6lc.csv]
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2026-09-29 DND-97: repair S6-LC mechanism defects A1/A2/A6/A7/A8; clarify mission gate
    Mines the unmerged cto/dnd93-fix-s6lc-g3 (#80) A1/A2 geometry work onto main
    and closes the mechanism defects the DND-93 fix left open.
    - A1 cell fit: gate the OWNED half-lane (0.74 mm); pawl root outboard, 0.45 leaf
    in-lane; SCAD re-placed (was BODY/2+0.10, reach 2.80 > 2.54 half-pitch).
    - A2 pawl spring: k from the 0.45 leaf (8x correction, release 0.020 N) + a hold
    gate held by the DND-76 P1 over-centre latch (compression hard stop).
    - A6 reliability: add G8 (explicitly UNRESOLVED, coupon C1 the evidence path).
    - A7/A8: restate the unloaded-write and regional/jam cases as explicit product
    limitations needin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
    [s6lc_cell.stl, s6lc_machine.scad]
2026-09-29 DND-98: independently re-ratify the corrected S6-LC purchased BOM
    Re-derives the CORRECTED (post-DND-93, DND-74 branch 1) S6-LC purchased BOM
    line by line and re-states the ceiling verdict against the DND-70/DND-72
    mission gate (<$250 purchased, excluding 3D-printed parts).
    Findings (sourced listings + CALCULATION; no print/purchase/measurement):
    - The corrected headline REPRODUCES: $226.77 parts / $263.05 delivered (x1.16),
    reconciling with s6lc.bom() and bom_s6lc.csv.
    - The $250 PURCHASED mission gate HOLDS: margin +$23.23.
    - The repo's stricter $250 DELIVERED convention FAILS: -$13.05. Both stated.
    - Growth since DND-73 is +$18.00 (NEMA17 -> NEMA23 lift re-price) + $69.00
    (six DND-91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
    [s6lc_bom_ratified.csv]
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2026-09-29 DND-107: reliability-first divergent machines (InventorBeta, mask + non-mask)
    Answers DND-104 requirement #1 from the reliability-first angle set by
    DND-103. Three materially different complete machines, none a trim of S6-LC
    and none like each other, each with ten-job allocation, sourced-class BOM,
    honest 7-stage timing decomposition, the DND-103 per-architecture reliability
    audit, and the cheapest no-print test that can kill it.
    - B1 shared driveshaft binary screw/nut memory (NON-MASK). Zero per-cell
    compliant decision elements; state is thread compression against hard stops.
    Reported FAIL_AS_DRAWN: the gang_sweep and lead_sweep show the timing-
    feasible and torque-feasible sets are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
    [b2b3_reliability_cell.scad]
2026-09-29 DND-104: reliability-first low-cost shape display + mask program (A1 selected)
    New candidate root 10-reliability-mask/ (08-current-design and 09-low-cost-variant
    untouched). Divergence screen of seven materially different architectures, a
    first-class repeated-mechanism reliability gate (DND-103), honest timing
    decomposition, purchased BOM, prototype ladder and decisive falsifier.
    Selected: A1 binary-latch + shared writer/reader - two-state columns held by an
    over-centre latch between two printed hard stops (zero compliant parts deciding
    correctness), a shared 2-axis gantry that writes only changed cells and then
    READS every cell back so a failed toggle is detected and re-driven, not silent.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
    [a1_binary_latch_cell.scad, bom_a1.csv, column.stl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]
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2026-09-29 DND-106: reliability-first cell/mask primitives (InventorAlpha)
    Attacks the S1/S2 family's reliability gate (DND-91 A6/G8): what has to
    work correctly 6,400 times?
    - R1 toggle-rocker row-shared state: one rocker per row (80 decisions,
    not 6,400), 80-cell blast radius, detectable.
    - R2 double-acting wedge-gate cell: positive hard stops both ways,
    platen-driven reset removes the A8 gravity-drop failure class.
    - R3 mechanical read-rod readback: 80 mechanical read points, converts
    a correlated error into a detectable/recoverable one; $4 allowance.
    - R4 shared return bar recorded REJECTED (correlated stall, no read path).
    Every primitive answers the full reliability-audit schema + ten
    fun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
    [reliability_cell.scad]
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2026-09-29 DND-111: analytic bound on the A1 writer/reader rate + single-cell read
    Replaces the DND-104 placeholder HEAD_RATE_CELLS_S = 1000.0 (1 ms/cell,
    assumption-class) with a first-principles derivation from sourced
    component-class kinematics + the placed A1 CAD (the DND-54 pattern: no
    print, DND-27).
    Findings (CALCULATION + CAD):
    - Stop-and-go is excluded at 5.08 mm pitch: 30 cells/s at the sourced X1C
    acceleration (20 m/s^2), 90 cells/s even at an aggressive 100 m/s^2.
    - Fly-over is traverse/actuation-bounded: per-cell time =
    max(traverse, actuation_or_read) + settle. At a credible 1.0 m/s gantry
    the head does 164.5 cells/s (band 71-228 across 0.5-1.5 m/s and
    snap-trigger vs full-sweep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
    [a1_reader_head.scad, reader_head.stl]
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2026-09-29 DND-113: correct the A1 read mechanism (resolve the DND-112 read finding)
    Accept the DND-112 audit: the rate bound stands, the single-cell read claim
    does not.
    - read_resolution_bound() now reports the state-dependent standoff:
    down-state spot 24.508 mm = 4.824 pitches at the 42 mm gap, ~441x
    neighbour/pocket return, corrected corner reach 4.081 mm; sets
    resolves_single_cell=False for the as-drawn top-face reader and
    binding_read_limit=state_dependent_standoff. +/-0.264 mm kept as up-state
    provenance only.
    - new common_height_read_target(): no existing A1 artifact reads a common
    plane; a latch-hinge flag is proposed (pending CAD).
    - new z_stroke_trade_study(): Z stroke per cell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
    [a1_reader_head.scad, reader_head.stl]
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
